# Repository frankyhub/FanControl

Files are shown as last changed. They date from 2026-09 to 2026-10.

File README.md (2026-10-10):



<div align="center">

|[:skull:ISSUE](https://github.com/frankyhub/FanControl/issues?q=is%3Aissue)|[:speech_balloon: Forum /Discussion](https://github.com/frankyhub/FanControl/discussions)|[:grey_question:WiKi](https://github.com/frankyhub/FanControl/wiki)||
|--|--|--|--|
| | | | |
<a href="https://github.com/frankyhub/FanControl/issues">|<a href="https://github.com/frankyhub/FanControl/discussions">|<a href="https://github.com/frankyhub/FanControl/releases">||
|| <a href="https://github.com/frankyhub/FanControl/pulse" alt="Activity">| <a href="https://github.com/frankyhub/FanControl/graphs/traffic">  |<a href="https://github.com/frankyhub?tab=stars"> |

---

## Story
In diesem Projekt wird ein ESP32-Kühlsystem aufgebaut, das Temperatur sowie Luftfeuchtigkeit in Echtzeit überwacht, Lüfter bei Grenzwerten automatisch steuert und eine komfortable Überwachung per Web-Dashboard und OLED-Display ermöglicht. Drei LEDs grün (TEMPERATUR OK), orange (WARNUNG: TEMP HOCH) und rot (KÜHLUNG AKTIV) zeigen den Temperaturstatus an. Liegt die IST-Temperatur über der SOLL-Temperatur leuchtet die rote LED und zwei Relais-Ausgänge schalten die beiden Lüfter ein. Der Temperatur-Grenzwert (ALARM-PARAMETER) kann am WEB-Dashboard mit der Tastatur oder der Maus verändert werden. 

Das Programm FanControR3.ino stellt einen dritten Relais-Ausgang zur Verfügung, der bereits mit der WARNUNG: TEMP HOCH (gelbe LED) einschaltet.

 ## FanControl WEB-Dashboard

  
 <br> <br>

 ## FanControl WEB-Dashboard Snapshot

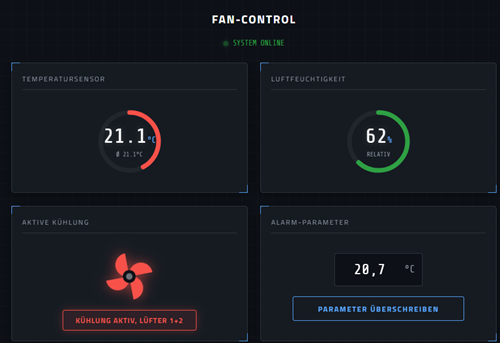
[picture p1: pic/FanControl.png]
   
<br> <br>

 ## FanControl OLED-Display

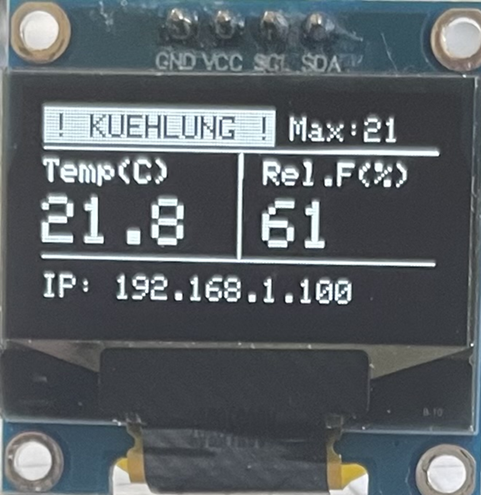
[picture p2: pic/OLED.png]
Bild

<br> <br>

## Hardware

| Stück | Beschreibung | 
| --- | --- |
|  1 |  ESP32 DevKit V4 | 
|  1 | 0.96" OLED Display |
| 1 |  Aktiver Piezo-Buzzer| 
|  5 |  LED rot |
|  1 |  LED gelb |
|  1 | LED grün| 
|  1 | Step Down Modul 12V->5V| 
|  1 | 12V Netzteil|
|  3 | Buchsen (Lüfter und Netzteil)|
|  3 | Stecker (Lüfter und Netzteil)|
|  1 | Schalter| 
| 5 |Widerstand 100 Ohm LED Frontseite|
| 2 |Widerstand 1200 Ohm LED Rückseite|
| 1 |Widerstand 10k Ohm DHT11/22 |
|  2 | Hot End Lüfter/ PC-Lüfter |
| 2 | Relais 5V |
| 1 |  DHT11 oder DHT22 Sensor |
| 1 | Sperrholzplatte 600x300x3mm  | 
| 1 | Drähte, Verbrauchsmaterial | 
| 1 | 3D Druckteile  | 
| 2| WAGO 5fach Klemmen  | 
| 1 | Holzkleber  | 
| -------- | -------- |  

##  Verdrahtung

| OLED-Display | ESP32 |
| --- | --- |
| VDD | Vin|
|GND| GND|
|SCK| GPIO 22|
|SDA| GPIO 21|
| -------- | -------- | 

### Gegebenenfalls den Sensor außerhalb des Gehäuses an einer geeigneten Messstelle montieren.

| DHT22-Sensor | ESP32 | 
| --- | --- |
|  VCC| Vin|
|Data | GPIO 4|
| GND (|GND|
| -------- | -------- | 

| Piezo-Buzzer | ESP32 | 
| --- | --- |
|Plus | GPIO 18|
|Minus | GND|
| -------- | -------- | 

| LED Ampel | ESP32 | 
| --- | --- |
|Rot |  GPIO 25|
|Gelb | GPIO 26 |
|Grün| GPIO 27|
| GND| GND|
| -------- | -------- | 
| Anzeige| Lüfter| 
|Rot Lüft.1| GPIO 16|
|Rot Lüft.2|  GPIO 17|
| -------- | -------- | 

|  Piezo-Buzzer  | ESP32 |  
| --- | --- |
|  Plus |GPIO 18|
| Minus | GND|
| -------- | -------- | 

|  Relais-Modul  | ESP32 | 
| --- | --- |
| VCC| Vin|
|GND| GND|
|IN1| GPIO 33|
| IN2| GPIO 32|
| IN2| GPIO 14 optional|
| -------- | -------- | 

### ESP32 Dev Kit V4 Boardverwalter: ESP32 Dev Module V3.3.11

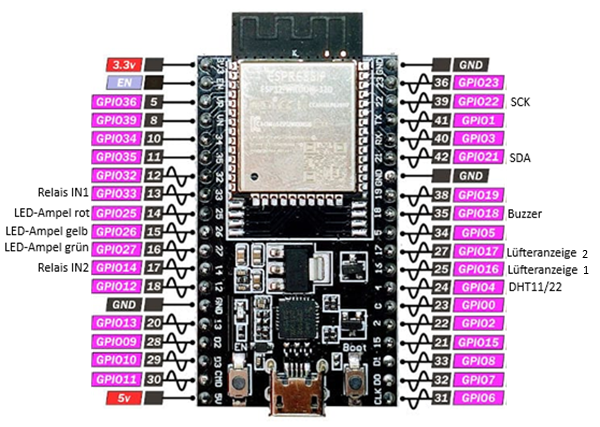
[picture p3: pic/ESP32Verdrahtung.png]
 
<br> <br>

### ESP32 Dev Kit V4 Shield

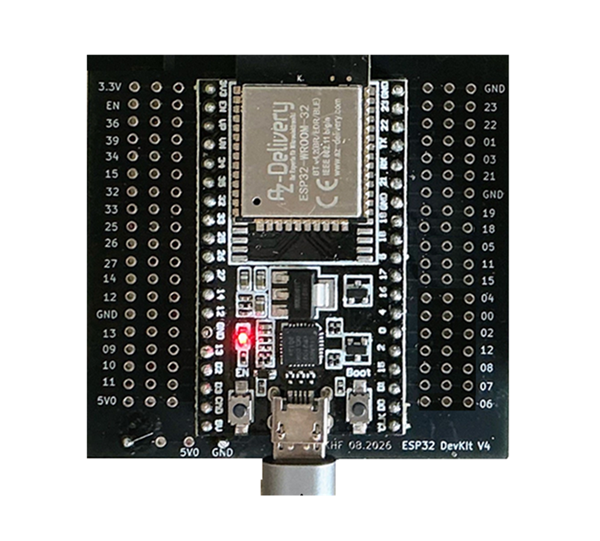
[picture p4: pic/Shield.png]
 
<br> <br>

### Das Relaismodul

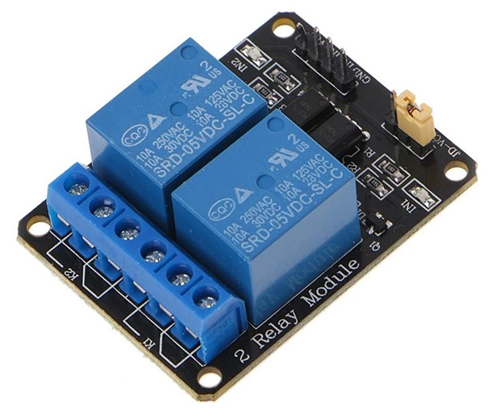
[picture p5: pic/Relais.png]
 
<br> <br>

Da der ESP32 nicht ausreichend Strom zum schalten der Lüfter liefert, verwenden wir ein Relaismodul.

Die Eingänge haben Optokoppler und bieten eine optische Trennung (Galvanische Isolierung). Sie trennen die 
empfindliche Steuerelektronik des Mikrocontrollers von der Lastseite (die Relaisspulen), damit Spannungsspitzen 
den Controller nicht beschädigen.

Die Spannungsversorgung des Relaisblocks erfolgt mit 5V.

Die externe Spannungsversorgung für die Lüfter wird am Wechslerkontakt der Relais angeschlossen. Je nach Lüftertyp können das auch 12V  (PC-Lüfter) sein.

Die Masse (GND) der externen Quelle und des Microcontrollers müssen verbunden sein (Common Ground). 

### Relais Verdrahtung

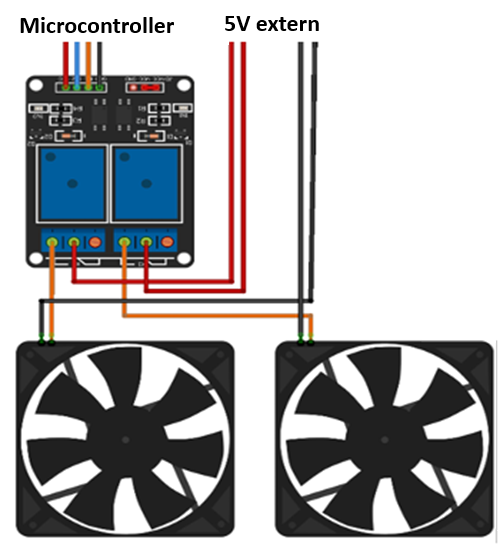
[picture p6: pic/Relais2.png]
 
<br> <br>

Der Code, um ein Relais mit dem ESP32 zu steuern, ist genauso einfach wie die Steuerung einer LED oder die Ansteuerung eines anderen Aktors. Der Relaisausgang schaltet mit einem LOW Signal. Bei einem HIGH Signal vom ESP32, ist das Relais in Ruhestellung. 

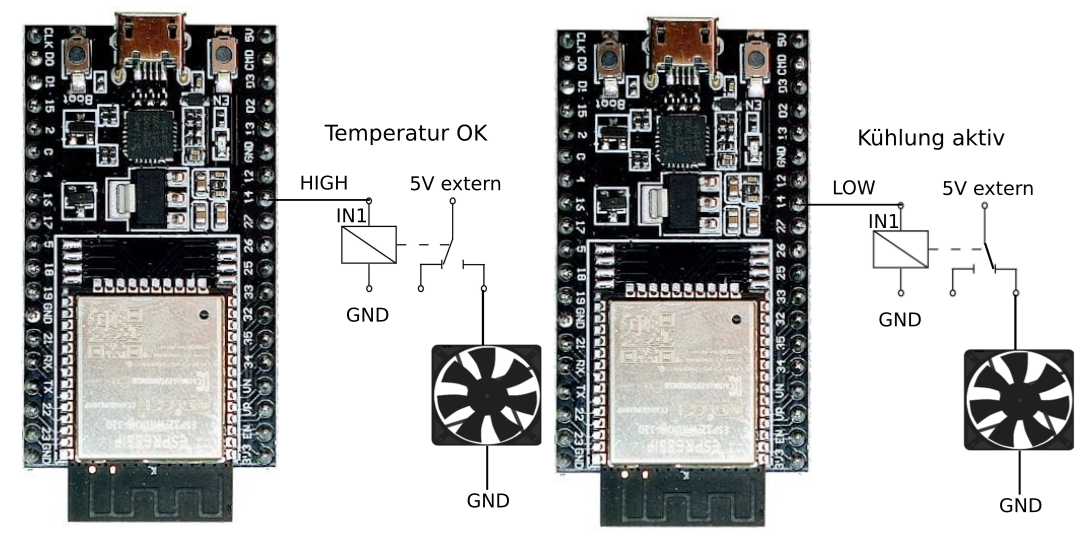
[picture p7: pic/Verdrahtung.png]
 
<br> <br>

### DHT11/22 Verdrahtung

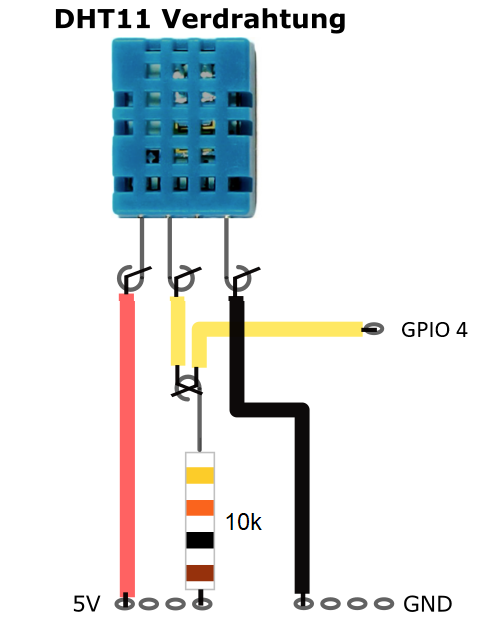
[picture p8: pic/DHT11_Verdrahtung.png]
 
<br> <br>

## 3D Druckteile

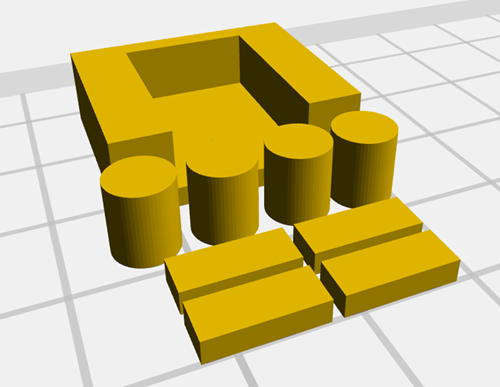
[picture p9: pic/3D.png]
 
<br> <br>

## FanControl Verdrahtung

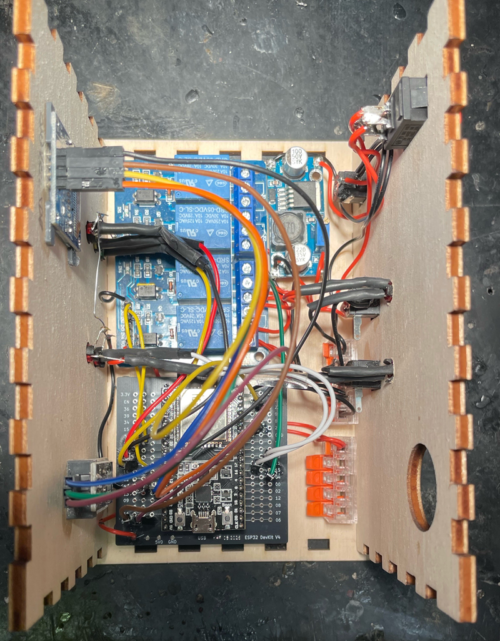
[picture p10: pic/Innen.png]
 
<br> <br>

## Gehäuse

### xtool Lasercutter Datei

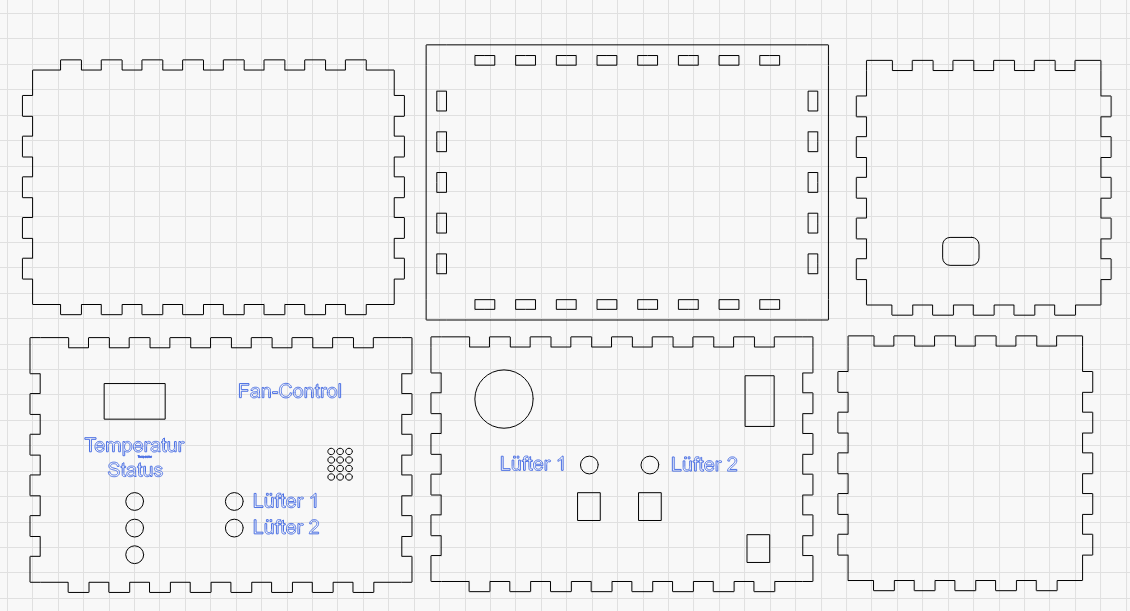
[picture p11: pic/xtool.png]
 
<br> <br>

### FanControl

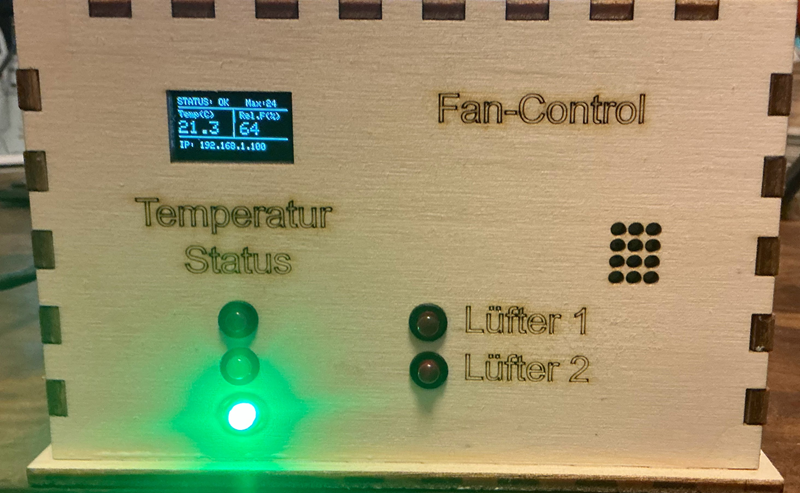
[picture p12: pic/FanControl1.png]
 
<br> <br>

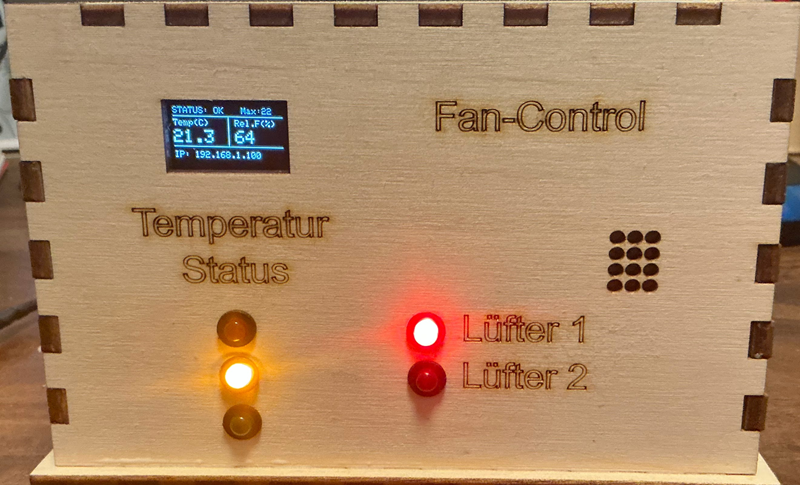
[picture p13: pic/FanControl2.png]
 
<br> <br>

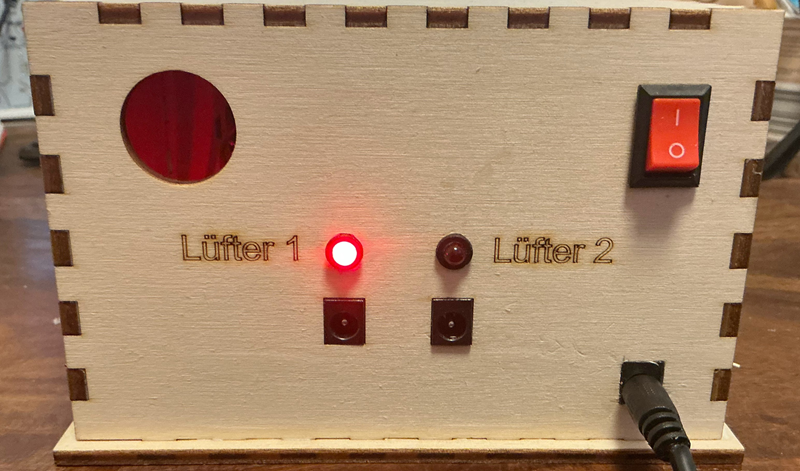
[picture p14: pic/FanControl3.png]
 
<br> <br>

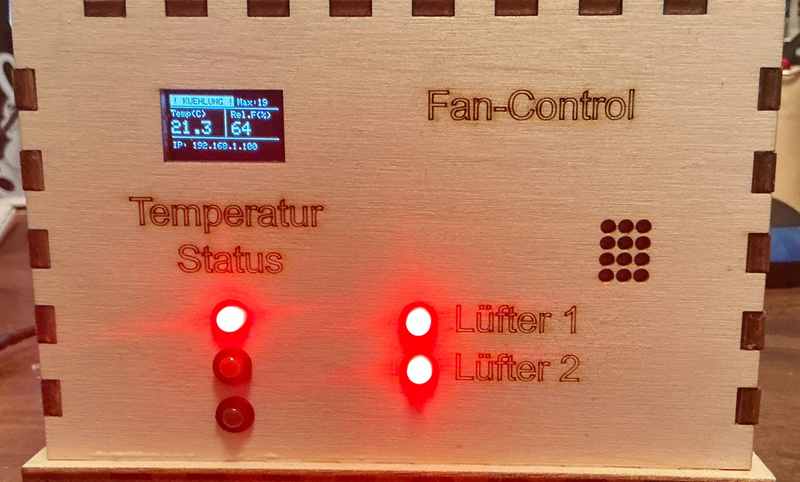
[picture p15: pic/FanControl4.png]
 
<br> <br>

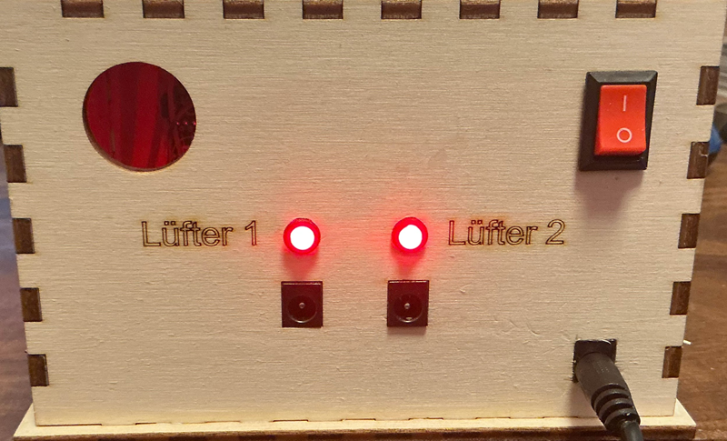
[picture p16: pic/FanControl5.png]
 
<br> <br>

---

<div style="position:absolute; left:2cm; ">   
<ol class="breadcrumb" style="border-top: 2px solid black;border-bottom:2px solid black; height: 45px; width: 900px;"> <p align="center"><a href="#oben">nach oben</a></p></ol>
</div>  

---

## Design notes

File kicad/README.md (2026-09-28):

## ESP32 Dev Kit Shield

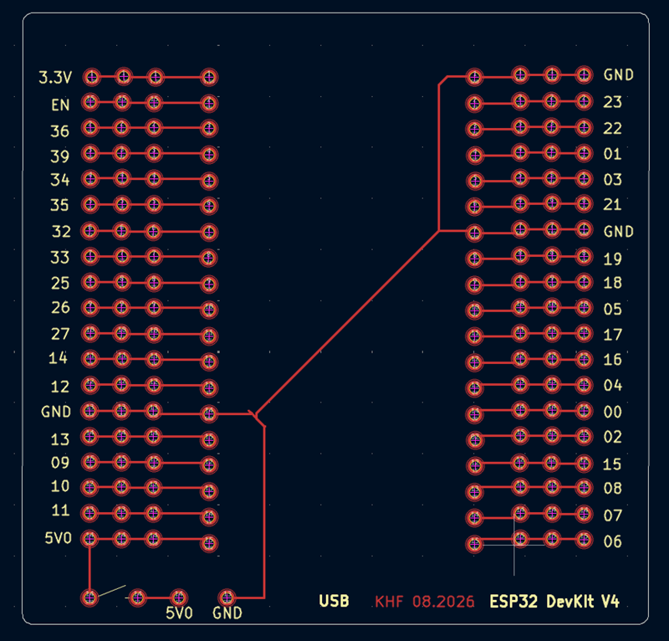
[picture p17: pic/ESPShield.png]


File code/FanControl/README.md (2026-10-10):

### Libraries

#include <WiFi.h>
<br>
#include <WebServer.h>
<br>
#include <Wire.h>

#include <Adafruit_GFX.h> <br>
//V1.12.6 https://github.com/adafruit/Adafruit-GFX-Library
<br><br>

#include <Adafruit_SSD1306.h> <br>
//V2.5.17 https://github.com/adafruit/Adafruit_SSD1306
<br><br>

#include <DHT.h> <br>
//V1.4.7 https://github.com/adafruit/DHT-sensor-library
<br><br>

Adafruit_Sensor <br>
V1.1.15 https://github.com/adafruit/Adafruit_Sensor

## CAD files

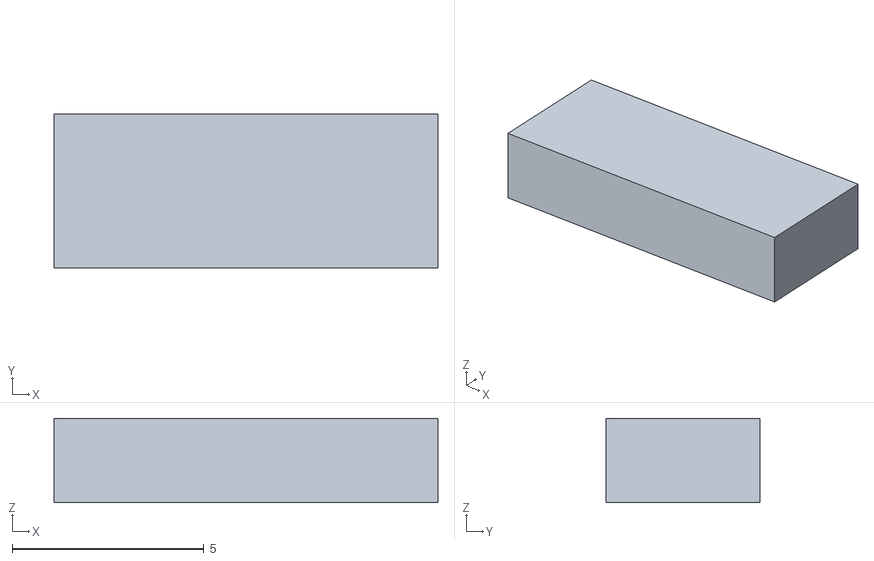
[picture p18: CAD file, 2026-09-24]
3D/OLED-Spacer.stl
10.0 x 4.00 x 2.20

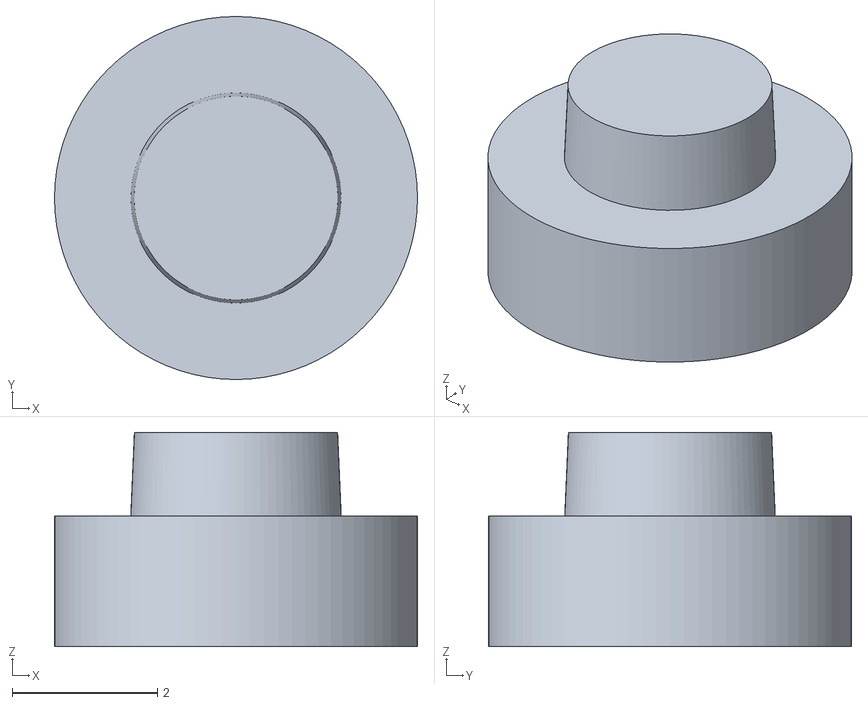
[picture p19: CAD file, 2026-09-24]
3D/Display-PIN.stl
5.00 x 5.00 x 2.95

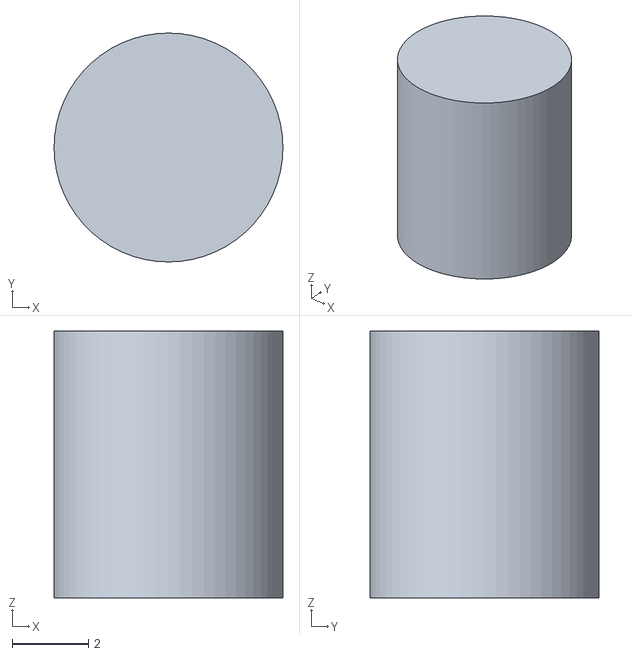
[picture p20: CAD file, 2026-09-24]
3D/ESP32_PIN_7mm.stl
6.00 x 6.00 x 7.00

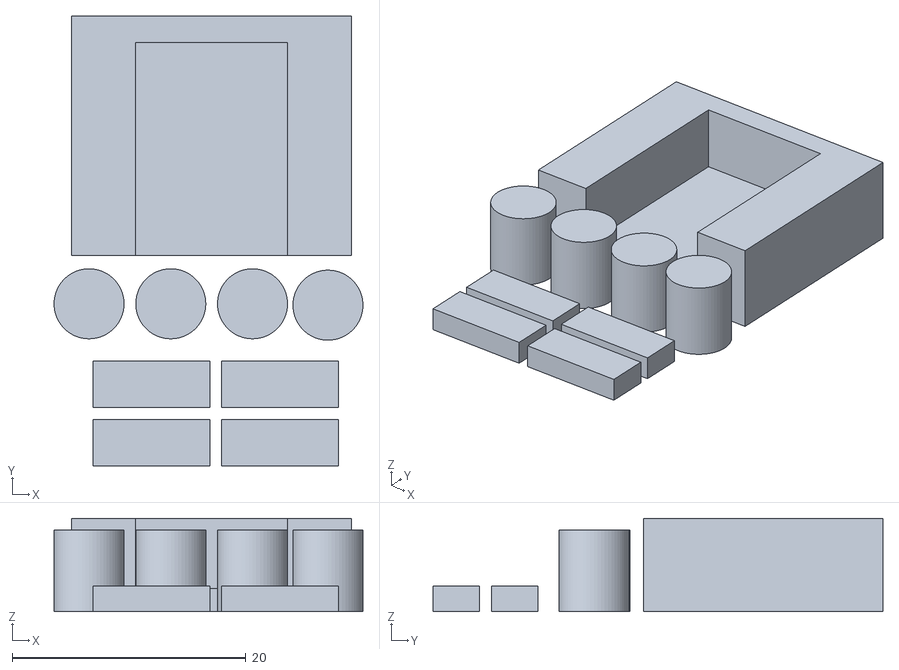
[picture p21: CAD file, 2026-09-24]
3D/FanControl.stl
26.5 x 38.5 x 8.00

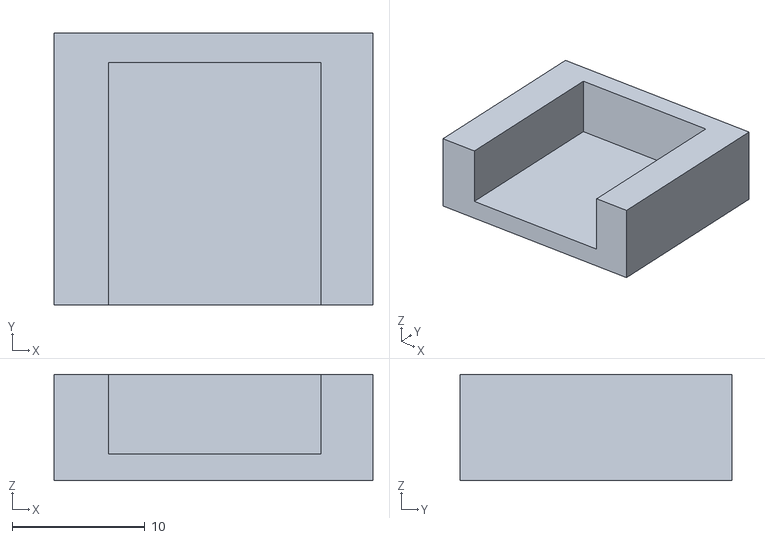
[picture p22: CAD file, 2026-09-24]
3D/DHT11-Halter.stl
24.0 x 20.5 x 8.00

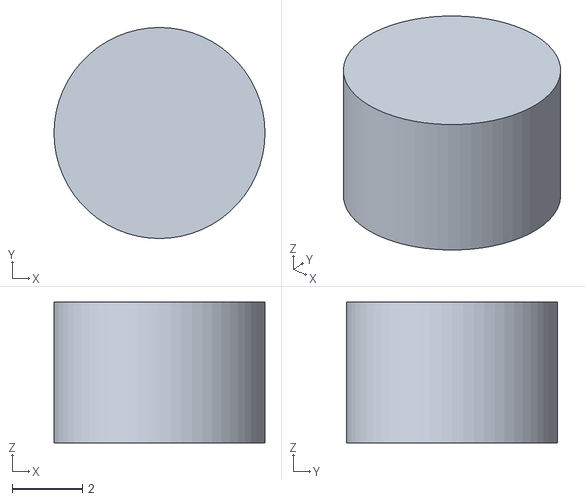
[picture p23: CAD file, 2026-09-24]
3D/ESP Spacer.stl
6.00 x 6.00 x 4.00

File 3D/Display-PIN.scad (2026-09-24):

//Platinen Pin 

$fn=80;
Rgr = 2.5;  //Radius PIN 
R1kl = 1.5; //Radius 1 Stift
R2kl = 1.4; //Radius 2 Stift
Sh = 1.8;     //Sockelhöhe

color("WhiteSmoke")
cylinder(h = Sh, r1=Rgr , r2=Rgr , center = true); //Sockel
translate(v = [0, 0, Sh/2])
color("WhiteSmoke")
cylinder(h = 2.3, r1 = R1kl, r2 = R2kl, center = true); //Pin

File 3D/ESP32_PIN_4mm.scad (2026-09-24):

//Platinen Pin ESP32 UNO Wetterstation
//4x

$fn=60;
Rgr = 3; //Radius PIN 
R1kl = 0; //Radius 1 Stift
R2kl = 0; //Radius 2 Stift
Sh = 4;       //Sockelhöhe


cylinder(h = Sh, r1=Rgr , r2=Rgr , center = true);
translate(v = [0, 0, Sh/2])
cylinder(h = 3, r1 = R1kl, r2 = R2kl, center = true);

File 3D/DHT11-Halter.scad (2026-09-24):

//DHT11-Halterung

difference() {
cube(size = [24,8,20.5], center = true);

translate(v = [-7.9 , -2, -8])
cube(size = [16,7,18.5]);
   
}

/*
translate(v = [-12, -4, 10])
cube(size = [24,4,1.5]);

translate(v = [-10, -2, -8])
color( "red", 1.0 )
cube(size = [12.5,5.8,18]);
*/

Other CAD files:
3D/ESP32_PIN_4mm.stl
3D/ESP32_PIN_7mm.scad
3D/ESP Spacer.scad
3D/OLED Spacer.scad

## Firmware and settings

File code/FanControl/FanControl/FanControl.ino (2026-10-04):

/*************************************************************************************************
                                      PROGRAMMINFO
**************************************************************************************************

  Funktion:  Lüftersteuerung mit WEB Server, 0,96" OLED Display, LED Ampel

**************************************************************************************************
  Version: 22.09.2026
**************************************************************************************************
  Board: ESP32 DEV KIT V4 Boardverwalter: ESP32 Dev Module V3.3.11
  
  https://raw.githubusercontent.com/espressif/arduino-esp32/gh-pages/package_esp32_index.json
  http://arduino.esp8266.com/stable/package_esp8266com_index.json
  https://adafruit.github.io/arduino-board-index/package_adafruit_index.json
**************************************************************************************************
  Libraries:
  
 <Adafruit_GFX.h> //V1.12.6 https://github.com/adafruit/Adafruit-GFX-Library
 <Adafruit_SSD1306.h> //V2.5.17 https://github.com/adafruit/Adafruit_SSD1306
 <DHT.h> //V1.4.7 https://github.com/adafruit/DHT-sensor-library
 Adafruit_Sensor Adafruit_Sensor1.1.15 https://github.com/adafruit/Adafruit_Sensor
 
**************************************************************************************************
  C++ Arduino IDE V1.8.19

**************************************************************************************************
  Einstellungen:
  https://dl.espressif.com/dl/package_esp32_index.json
  http://dan.drown.org/stm32duino/package_STM32duino_index.json
  http://arduino.esp8266.com/stable/package_esp8266com_index.json

  Benötigte Komponenten:

  DHTESP32 NodeMcu Entwicklungsboard
  2x Breadboard 400
  0.96" OLED Display
  Aktiver Piezo-Buzzer
  LED Ampel Modul
  2x Hot End Lüfter
  2 Kanal Relais 5V
  Jumper Wire Kabel
  Jumper Kabel Buchse-Stecker
  DHT11 oder DHT22 Sensor

  Verdrahtung:
  Komponente  Pin (Modul) Anschluss (ESP32 / System)
  OLED-Display  VDD Vin
              GND GND
              SCK GPIO 22
              SDA GPIO 21
  DHT11-Sensor  VCC (links) Vin
              Data (Mitte-links)  GPIO 4
              GND (rechts)  GND
              Piezo-Buzzer  Plus (+)  GPIO 18
              Minus (-) GND
  LED-Ampel R (Rot)   GPIO 25
          Y (Gelb)  GPIO 26 
          G ( Grün) GPIO 27
          GND GND

  Relais-Modul  VCC Vin
              GND GND
              IN1 GPIO 33
              IN2 GPIO 32
  Relais-Modul (Schraubklemmen)
              COM (Mitte)  
              Vin (ESP32)
  Lüfter 1 & 2  Rotes Kabel (+) NO (links am Relais)
  Schwarzes Kabel (-) GND (ESP32)


  OLED-Display  VDD Vin
              GND GND
              SCK GPIO 22
              SDA GPIO 21

  DHT11-Sensor
            VCC (links) Vin
            Data (Mitte-links) GPIO 4
            GND (rechts) GND
  Piezo-Buzzer
            Plus (+)GPIO 18
            Minus (-) GND

  LED-Ampel
            R (Rot)   GPIO 25
            Y (Gelb)  GPIO 26
            G ( Grün) GPIO 27
            GND GND
  Relais-Modul
            VCC Vin
            GND GND
            IN1 GPIO 33
            IN2 GPIO 32
  Relais-Modul (Schraubklemmen)
            COM (Mitte)  Vin (ESP32)

  Lüfter 1 & 2
            Rotes Kabel (+) NO (links am Relais)
            Schwarzes Kabel (-) GND (ESP32)

**************************************************************************************************/

#include <WiFi.h>
#include <WebServer.h>
#include <Wire.h>
#include <Adafruit_GFX.h>
#include <Adafruit_SSD1306.h>
#include <DHT.h>

// Importiert das externe HTML-Dashboard
#include "web_page.h"

// --- WLAN-KONFIGURATION ---
const char* wifi_ssid = "xxx;
const char* wifi_pass = "xxx";

// --- PIN-BELEGUNG (HARDWARE) ---
#define DHT_PIN 4          // Daten-Pin DHT11
#define PIEZO_PIN 18       // Buzzer (Pluspol)
#define LED_RED 25         // Status: Kritisch
#define LED_YELLOW 26      // Status: Warnung
#define LED_GREEN 27       // Status: Normal
#define FAN_RELAY_1 33     // Lüfter 1
#define FAN_RELAY_2 32     // Lüfter 2

// --- RELAIS-STEUERUNG ---
// Die meisten Relais schalten bei LOW (Active LOW)
#define RELAY_ACTIVE LOW
#define RELAY_INACTIVE HIGH

// --- SENSOR-INIT ---
DHT dhtSensor(DHT_PIN, DHT22);

// --- OLED-INIT ---
#define OLED_W 128
#define OLED_H 64
// Standard I2C-Adresse 0x3C für 128x64 Displays
Adafruit_SSD1306 oledDisplay(OLED_W, OLED_H, &Wire, -1);

WebServer webDashboard(80); // HTTP Web-Server auf Port 80

// --- GLOBALE VARIABLEN ---
float tempC = 0.0;
float humidity = 0.0;
float maxTempLimit = 30.0; // Schwellenwert (über WLAN anpassbar)
float smoothedTemp = 0.0;  // Gefilterter Temperaturwert

int systemStatus = 0; // 0=Grün, 1=Gelb, 2=Rot
bool coolingActive = false; // Status der Lüfter

// --- Filter: Gleitender Durchschnitt zur Rauschunterdrückung ---
const int filterSize = 10;
float tempBuffer[filterSize];
int bufferIndex = 0;
float tempSum = 0;

// --- Timer für Multitasking (ersetzt blockierendes delay) ---
unsigned long timeLastSensor = 0;
unsigned long timeLastDisplay = 0;

// --- Variablen für akustische Signale ---
bool isBuzzerOn = false;
int audioMode = 0;
unsigned long audioTimer = 0;
bool actionTriggered = false; // Verhindert Endlosschleife des Sounds
int melodyStep = 0;           // Zähler für die Melodie-Noten

// --- AUDIO-ROUTINE (NON BLOCKING) ---
void updateAudioAlerts() {
  if (!isBuzzerOn) {
    noTone(PIEZO_PIN);
    return;
  }
  unsigned long currentMillis = millis();

  // Modus 1: Schöner Warn-Alarm (Eleganter Akkord, 4x wiederholt)
  if (audioMode == 1) {
    // 4x A-Moll Arpeggio mit markanten Pausen (0) dazwischen
    int alertNotes[] = {
      880, 1047, 1318, 0, 0, // 1. Mal
      880, 1047, 1318, 0, 0, // 2. Mal
      880, 1047, 1318, 0, 0, // 3. Mal
      880, 1047, 1318        // 4. Mal
    };
    int numNotes = 18;

    // Wechselt die Note alle 110ms
    if (currentMillis - audioTimer > 110) {
      audioTimer = currentMillis;
      if (melodyStep < numNotes) {
        if (alertNotes[melodyStep] == 0) {
          noTone(PIEZO_PIN); // Kurze Pause zwischen den Akkorden
        } else {
          tone(PIEZO_PIN, alertNotes[melodyStep]);
        }
        melodyStep++;
      } else {
        isBuzzerOn = false;
        noTone(PIEZO_PIN);
      }
    }
  }
  // Modus 2: "System Bereit" / Deaktivierung (Die 6-Noten Level-Up Melodie)
  else if (audioMode == 2) {
    // Eine komplexe, aufsteigende A-Dur Melodie
    int successNotes[] = {440, 554, 659, 880, 1108, 1318};
    int numNotes = 6;

    // Wechselt die Note alle 90ms (fließend und schnell)
    if (currentMillis - audioTimer > 90) {
      audioTimer = currentMillis;
      if (melodyStep < numNotes) {
        tone(PIEZO_PIN, successNotes[melodyStep]);
        melodyStep++;
      } else {
        isBuzzerOn = false;
        noTone(PIEZO_PIN);
      }
    }
  }
}

void playActivationChime() {
  if (!actionTriggered) {
    isBuzzerOn = true;
    audioMode = 1;
    melodyStep = 0;
    audioTimer = millis();
    actionTriggered = true; // Sperre: Nur einmal abspielen
  }
}

void playDeactivationChime() {
  isBuzzerOn = true;
  audioMode = 2;
  melodyStep = 0;
  audioTimer = millis();
}

// --- WEB-SERVER ROUTINEN ---

// Route: "/" (Startseite)
void routeHomePage() {
  String html = index_html;
  // Aktuellen Grenzwert in das HTML-Template einfügen
  html.replace("%LIMIT%", String(maxTempLimit, 1));
  webDashboard.send(200, "text/html", html);
}

// Route: "/status" (JSON-Daten für AJAX-Updates)
void routeStatusJson() {
  char jsonBuffer[150];
  snprintf(jsonBuffer, sizeof(jsonBuffer),
           "{\"temp\":\"%.1f\",\"hum\":\"%.0f\",\"avg\":\"%.1f\",\"status\":%d}",
           smoothedTemp, humidity, smoothedTemp, systemStatus
          );
  webDashboard.send(200, "application/json", jsonBuffer);
}

// Route: "/set" (Einstellungen aktualisieren)
void routeSetLimit() {
  if (webDashboard.hasArg("threshold")) {
    maxTempLimit = webDashboard.arg("threshold").toFloat();
    Serial.println("Neues Limit gesetzt: " + String(maxTempLimit));
  }
  webDashboard.send(200, "text/plain", "OK");
}

// --- DISPLAY-UPDATE (GETEILTES LAYOUT MIT IP-FIX) ---
void refreshOLED() {
  oledDisplay.clearDisplay();

  // -- KOPFZEILE: STATUS & GRENZWERT (Oben) --
  if (coolingActive) {
    // Wenn Kühlung aktiv: Invertierter Block
    oledDisplay.fillRect(0, 0, 75, 11, WHITE);
    oledDisplay.setTextColor(BLACK);
    oledDisplay.setCursor(3, 2);
    oledDisplay.setTextSize(1);
    oledDisplay.print("! KUEHLUNG !");
  } else {
    // Normalbetrieb
    oledDisplay.setTextColor(WHITE);
    oledDisplay.setTextSize(1);
    oledDisplay.setCursor(0, 2);
    oledDisplay.print("STATUS: OK");
  }

  // Grenzwert (Limit) oben rechts
  oledDisplay.setTextColor(WHITE);
  oledDisplay.setTextSize(1);
  oledDisplay.setCursor(80, 2);
  oledDisplay.print("Max:");
  oledDisplay.print(maxTempLimit, 0);

  // Horizontale Trennlinie oben
  oledDisplay.drawLine(0, 12, 128, 12, WHITE);

  // -- HAUPTDATEN: GETEILTE ANSICHT (Mitte) --
  // Linke Seite: Temperatur
  oledDisplay.setTextSize(1);
  oledDisplay.setCursor(0, 16);
  oledDisplay.print("Temp(C)");
  oledDisplay.setTextSize(2);
  oledDisplay.setCursor(0, 28);
  oledDisplay.print(smoothedTemp, 1);
  Serial.println ("Temp(C)");
  Serial.println (smoothedTemp);

  // Rechte Seite: Luftfeuchtigkeit
  oledDisplay.setTextSize(1);
  oledDisplay.setCursor(72, 16);
  oledDisplay.print("Rel.F(%)");
  oledDisplay.setTextSize(2);
  oledDisplay.setCursor(72, 28);
  oledDisplay.print(humidity, 0);

  // Vertikale Trennlinie in der Mitte der Daten
  oledDisplay.drawLine(64, 12, 64, 46, WHITE);

  // Horizontale Trennlinie unten
  oledDisplay.drawLine(0, 46, 128, 46, WHITE);

  // -- FUSSZEILE: NETZWERK & IP (Unten) --
  oledDisplay.setTextSize(1);
  oledDisplay.setCursor(0, 52);

  if (WiFi.status() == WL_CONNECTED) {
    oledDisplay.print("IP: ");
    oledDisplay.print(WiFi.localIP());
    Serial.println("IP: ");
    Serial.println(WiFi.localIP());
  } else {
    oledDisplay.print("WLAN GETRENNT");
    Serial.println("WLAN GETRENNT");
  }

  oledDisplay.display(); // Bild auf das OLED übertragen
}

// --- SETUP-ROUTINE ---
void setup() {
  Serial.begin(115200);
  Serial.println(WiFi.localIP());
  // Pin-Modi konfigurieren
  pinMode(PIEZO_PIN, OUTPUT);
  pinMode(LED_RED, OUTPUT);
  pinMode(LED_YELLOW, OUTPUT);
  pinMode(LED_GREEN, OUTPUT);
  pinMode(FAN_RELAY_1, OUTPUT);
  pinMode(FAN_RELAY_2, OUTPUT);

  // Relais initial ausschalten
  digitalWrite(FAN_RELAY_1, RELAY_INACTIVE);
  digitalWrite(FAN_RELAY_2, RELAY_INACTIVE);

  // Sensor und Puffer initialisieren
  dhtSensor.begin();
  for (int i = 0; i < filterSize; i++) tempBuffer[i] = 0;

  // OLED über I2C starten
  Wire.begin(21, 22);
  if (!oledDisplay.begin(SSD1306_SWITCHCAPVCC, 0x3C)) {
    Serial.println("OLED Initialisierung fehlgeschlagen");
    for (;;); // Stoppt Ausführung bei Display-Fehler
  }

  // Boot-Bildschirm
  oledDisplay.clearDisplay();
  oledDisplay.setTextColor(WHITE);
  oledDisplay.setTextSize(1);
  oledDisplay.setCursor(20, 25);
  oledDisplay.println("Verbinde WLAN...");
  Serial.println("Verbinde WLAN...");
  oledDisplay.display();

  // WLAN-Verbindung herstellen
  WiFi.begin(wifi_ssid, wifi_pass);
  while (WiFi.status() != WL_CONNECTED) delay(500);

  // Web-Server Routinen zuweisen und starten
  webDashboard.on("/", routeHomePage);
  webDashboard.on("/status", routeStatusJson);
  webDashboard.on("/set", routeSetLimit);
  webDashboard.begin();
}

// --- LOGIK-AUSWERTUNG ---
void evaluateConditions() {
  bool isCritical = false;

  // Status 0: Normal (Grün)
  if (smoothedTemp < (maxTempLimit - 2.0)) {
    systemStatus = 0;
    digitalWrite(LED_GREEN, HIGH);
    digitalWrite(LED_YELLOW, LOW);
    digitalWrite(LED_RED, LOW);
    actionTriggered = false; // Reset für den nächsten Aktivierungs-Sound
  }
  // Status 1: Warnung (Gelb)
  else if (smoothedTemp >= (maxTempLimit - 2.0) && smoothedTemp < maxTempLimit) {
    systemStatus = 1;
    digitalWrite(LED_GREEN, LOW);
    digitalWrite(LED_YELLOW, HIGH);
    digitalWrite(LED_RED, LOW);
    actionTriggered = false; // Reset
  }
  // Status 2: Kritisch (Rot)
  else {
    systemStatus = 2;
    digitalWrite(LED_GREEN, LOW);
    digitalWrite(LED_YELLOW, LOW);
    digitalWrite(LED_RED, HIGH);
    isCritical = true;
  }

  // Relais & Lüfter schalten
  if (isCritical && !coolingActive) {
    digitalWrite(FAN_RELAY_1, RELAY_ACTIVE);
    digitalWrite(FAN_RELAY_2, RELAY_ACTIVE);
    coolingActive = true;
    playActivationChime(); // Spielt den eleganten Warn-Gong
  }
  else if (!isCritical && coolingActive) {
    digitalWrite(FAN_RELAY_1, RELAY_INACTIVE);
    digitalWrite(FAN_RELAY_2, RELAY_INACTIVE);
    coolingActive = false;
    playDeactivationChime(); // Spielt die Level-Up Melodie
  }
}

// --- HAUPTSCHLEIFE ---
void loop() {
  // 1. Web-Anfragen verarbeiten (Muss kontinuierlich laufen)
  webDashboard.handleClient();

  // 2. Audio-Signale im Hintergrund verwalten
  updateAudioAlerts();

  unsigned long currentMillis = millis();

  // 3. Sensor alle 2 Sekunden auslesen
  if (currentMillis - timeLastSensor >= 2000) {
    timeLastSensor = currentMillis;

    float t = dhtSensor.readTemperature();
    float h = dhtSensor.readHumidity();

    if (!isnan(t) && !isnan(h)) {
      tempC = t;
      humidity = h;

      // Gleitenden Durchschnitt berechnen
      tempSum = tempSum - tempBuffer[bufferIndex];
      tempBuffer[bufferIndex] = tempC;
      tempSum = tempSum + tempBuffer[bufferIndex];
      bufferIndex = (bufferIndex + 1) % filterSize;

      smoothedTemp = (tempSum == 0) ? tempC : (tempSum / filterSize);
      if (smoothedTemp < 1) smoothedTemp = tempC; // Verhindert 0-Werte beim Start
    }

    evaluateConditions();
  }

  // 4. OLED-Display jede Sekunde aktualisieren
  if (currentMillis - timeLastDisplay >= 1000) {
    timeLastDisplay = currentMillis;
    refreshOLED();
  }
}

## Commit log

2026-09-22 V22092026
    Updated README.md to include detailed project information, hardware specifications, wiring instructions, and laser cutter file.
2026-09-22 V22092026
    Updated hardware section and wiring table in README.
2026-09-22 V22092026
    Updated hardware and wiring sections with corrected formatting and additional components.
2026-09-22 V22092026
    Added OLED display functionality to the ESP32 cooling system project description.
2026-09-22 V22092026
    Added detailed explanation of JD-VCC, relay power requirements, and connection methods.
2026-09-22 V22092026
    Added section about relay module and its power requirements.
2026-09-23 V22092026
    Updated the section on relay modules for clarity and corrected image paths. Added details about power supply and connection recommendations.
2026-09-23 V22092026
    Updated the README to clarify the use of a relay module with the ESP32 and added images.
2026-09-23 V22092026
    Corrected typos and improved clarity in the explanation of relay operation and power supply connections.
2026-09-23 V22092026
    Updated project description to include adjustable temperature threshold and changed material thickness for the case.
2026-09-24 V22092026
    Corrected LED quantities and GPIO mappings in the table.
2026-09-24 V22092026
    Removed unnecessary lines and cleaned up the table format for the relay module and other components.
2026-09-24 ![Bild](/pic/Relais.png)
    Removed unnecessary blank lines and added section for ESP32 Dev Kit V4.
2026-09-27 V22092026
    Added instructions for external sensor placement.
2026-09-28 V22092026
    Updated the explanation for controlling a relay with ESP32.
2026-09-28 V22092026
    Added wiring section and multiple images for fan control.
2026-09-29 V28092026
    Clarified power supply requirements for relays and fans.
2026-09-29 V28092026
    Updated wording for clarity regarding relay power supply and fan voltage.
2026-10-04 V040102026
    Added library includes for WiFi, WebServer, Wire, Adafruit GFX, Adafruit SSD1306, and DHT.
2026-10-04 V040102026
    Added additional library includes for WiFi, WebServer, Wire, Adafruit_GFX, Adafruit_SSD1306, and DHT.
2026-10-10 V10102026
    Added wiring section for relays and DHT11/22.
2026-10-12 V12102024
    Added project description for ESP32 cooling system.
